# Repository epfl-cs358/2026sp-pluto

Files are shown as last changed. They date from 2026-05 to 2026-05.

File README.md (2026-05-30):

<div align="center">

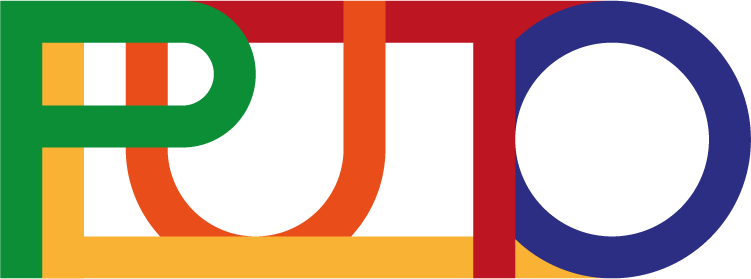
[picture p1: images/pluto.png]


# 🐶 Pluto

**A compact 12-DOF quadruped robot with ESP32 gait control, calibrated servo actuation, sensor reactions, controller-side speech commands, and simulation assets.**








</div>

<p align="center">
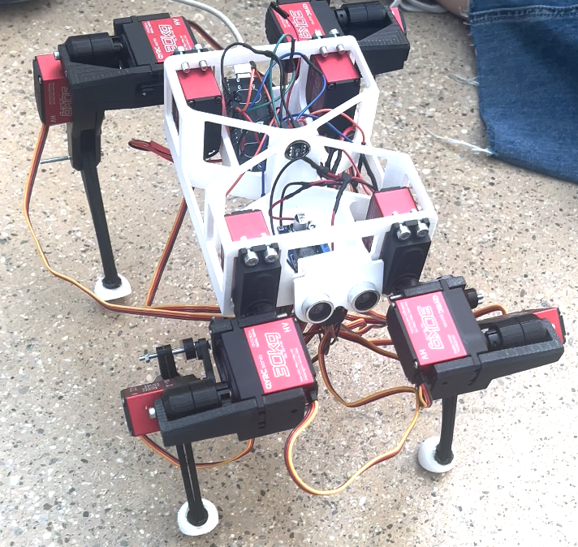
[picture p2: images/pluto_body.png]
Pluto physical robot
  
</p>

---

## 🧭 Quick Navigation

<table>
<tr>
<td width="25%" align="center" valign="top">
<a href="ASSEMBLY.md"><strong>Build Pluto</strong></a><br>
Assembly steps, leg construction, body integration, and final checks.
</td>
<td width="25%" align="center" valign="top">
<a href="WIRING_ELECTRICAL.md"><strong>Wire Pluto</strong></a><br>
Power path, common ground, PCA9685, sensors, and safety checks.
</td>
<td width="25%" align="center" valign="top">
<a href="src/esp/README.md"><strong>ESP32 Firmware</strong></a><br>
Gaits, IK, servos, sensors, serial commands, and WiFi/UDP.
</td>
<td width="25%" align="center" valign="top">
<a href="src/control/README.md"><strong>Controller UI</strong></a><br>
NiceGUI, keyboard/gamepad input, speech commands, and telemetry.
</td>
</tr>
<tr>
<td width="25%" align="center" valign="top">
<a href="CAD_FILES.md"><strong>Meshes</strong></a><br>
Current STL inventory and MuJoCo mesh usage.
</td>
<td width="25%" align="center" valign="top">
<a href="src/comm/README.md"><strong>Protocol</strong></a><br>
Shared C++/Python UDP packet and message format.
</td>
<td width="25%" align="center" valign="top">
<a href="SIMULATION.md"><strong>Simulation</strong></a><br>
PyBullet UI path, MuJoCo bridge, and current limitations.
</td>
<td width="25%" align="center" valign="top">
<a href="TROUBLESHOOTING.md"><strong>Troubleshooting</strong></a><br>
First-time setup, firmware, power, sensors, and WiFi issues.
</td>
</tr>
</table>

---

## 📚 Table of Contents

<table>
<tr>
<td width="33%" valign="top">

- [Project Context](#project-context)
- [What Pluto Can Do](#what-pluto-can-do)
- [Current Status](#current-status)
- [Quick Start](#quick-start)

</td>
<td width="33%" valign="top">

- [System Architecture](#system-architecture)
- [Hardware Overview](#hardware-overview)
- [Software Overview](#software-overview)
- [Simulation](#simulation)

</td>
<td width="33%" valign="top">

- [Configuration and Tuning](#configuration-and-tuning)
- [Repository Structure](#repository-structure)
- [Known Limitations](#known-limitations)
- [Detailed Technical Reference](#detailed-technical-reference)

</td>
</tr>
</table>

---

## 🧠 Project Context

<table>
<tr>
<td width="50%" valign="top">

### 🎯 Vision

Pluto is designed as a reusable quadruped robotics platform rather than a single-purpose demo. The goal is to make a small robot that can stand, walk, trot, gallop, react to simple sensor events, and accept commands through serial, WiFi, UI controls, and speech.

The same concepts appear across the firmware, controller, and simulation code: leg geometry, foot targets, inverse kinematics, gait phases, calibrated servo limits, and compact command messages.

</td>
<td width="50%" valign="top">

### 🎓 Course Context

Pluto was developed as part of **CS-358 Making Intelligent Things** at **EPFL**.

The repository documents both the final implementation and the current work-in-progress state so future development can continue from the same hardware, firmware, controller, protocol, and simulation foundation.

</td>
</tr>
</table>

### 🧱 Main Implementation Layers

| Layer | Role |
| --- | --- |
| ESP32 firmware | Servo control, gait execution, ultrasonic sensing, optional microphone sensing, serial testing, and WiFi/UDP command handling |
| Python tooling | NiceGUI control hub, keyboard/gamepad input, speech command handling, telemetry display, and simulation control |
| Shared communication | C++ and Python packet/message definitions kept aligned |
| CAD and simulation assets | 3D-printing meshes, simulation meshes, `pluto.xml`, PyBullet-facing code, and MuJoCo bridge |

---

## 🚀 What Pluto Can Do

<table>
<tr>
<td width="50%" valign="top">

### 🤖 Robot Side

- Drive 12 servo joints through a PCA9685 PWM driver.
- Use per-joint calibration for coxa, femur, and tibia angles.
- Run stand, stop, forward, backward, left turn, right turn, walk, trot, gallop, flip, bow, sit, and paw motion logic.
- Update gait motion every 20 ms.
- Stop motion when the ultrasonic sensor detects a close wall.
- Keep microphone support available in the source tree; the compile-time feature flag and clap-energy walking toggle are currently disabled in `main.cpp`.
- Accept serial monitor commands for gait testing and servo trimming.
- Receive UDP commands over WiFi when configured on the same network.

</td>
<td width="50%" valign="top">

### 💻 Computer Side

- Launch a NiceGUI control hub.
- Use keyboard and browser gamepad input.
- Send repeated `MOVE_BY` messages while movement input is active; firmware maps those vectors to forward, backward, left turn, right turn, or stop.
- Trigger sit, flip, bow, give paw, and stop commands from the UI.
- Run Vosk speech recognition on the controller computer.
- Display acknowledgement and distance telemetry.
- Open the Python PyBullet simulation path.
- Maintain shared message definitions with the firmware.

</td>
</tr>
</table>

---

## 📌 Current Status

| Area | Status | Notes |
| --- | --- | --- |
| Physical robot | In progress | Main build and wiring docs exist; final gait validation still needed |
| Servo control | Implemented | Calibration lives in `src/esp/legs/leg_data.h` |
| Gaits | Implemented, tuning needed | Walk, trot, gallop, left/right turn, bow, paw, stand, and stop logic exist |
| Sensors | Implemented, tuning needed | Ultrasonic wall stop is active; microphone support exists but `PLUTO_ENABLE_MICROPHONE` and clap-control are currently commented out |
| Controller UI | Implemented | Connect button, mDNS scan, movement input, sit/flip/bow/give-paw quick actions, telemetry, speech worker |
| WiFi/UDP | Implemented, enabled in firmware | Add WiFi credentials in `setup()`; the controller discovers `_pluto._udp.local` with zeroconf |
| Meshes | Updated | 3D-printing meshes live in `src/3D printing mesh`; simulation meshes and `pluto.xml` live in `src/sim/sim_mesh` |
| PyBullet | Partial | UI path exists, but visual meshes still reference old generic filenames |
| MuJoCo | Partial | Model and C++ bridge exist, but not yet a validated physical twin |

---

## ⚡ Quick Start

### 📦 1. Install Requirements

For the Python controller:

- Python 3.13
- Desktop environment for the browser UI and simulation windows
- Audio permission if using speech commands

For the ESP32 firmware:

- PlatformIO Core or the PlatformIO VS Code extension
- ESP32 board connected over USB
- Pluto hardware assembled or a safe bench setup

For the physical robot:

- Common ground between ESP32, PCA9685, servo power, sensors, and battery system
- Buck converter output checked with a multimeter
- Servo calibration checked before full gait tests

### ▶️ 2. Run the Controller

macOS/Linux:

```bash
bash run.sh
```

Windows:

```cmd
run.bat
```

Open:

```text
http://localhost:8090
```

Useful options:

```bash
bash run.sh --reinstall
bash run.sh --port 8081
```

Manual setup, if needed:

```bash
python3.13 -m venv .venv
source .venv/bin/activate
pip install -r requirements.txt
python src/control/main.py --port 8090
```

### 🔌 3. Build and Flash the ESP32

```bash
pio run
pio run -t upload
pio device monitor -b 115200
```

If the upload port is not detected automatically:

```bash
pio device list
pio run -t upload --upload-port /dev/cu.usbserial-XXXX
```

Expected startup behavior:

- PCA9685 initializes at 50 Hz.
- Enabled sensors initialize.
- Pluto enters a stand pose.
- The serial monitor prints available commands.

### 📶 4. Configure WiFi Control

WiFi support is currently enabled in `src/esp/main.cpp`:

```cpp
#define PLUTO_ENABLE_WIFI
```

Then:

1. Configure access points with `PLUTO_SERVER.addAP(...)`.
2. Make sure the computer and ESP32 are on the same network.
3. Run the controller and open `/controller`.
4. Press `Connect & Take Control`; the Python client scans for Pluto via mDNS/zeroconf and then performs the UDP handshake.

See [SOFTWARE_WIFI.md](SOFTWARE_WIFI.md).

---

## 🚀 Build Pluto From Scratch

This is the recommended order for a new team starting with only the repository, parts, and a 3D printer.

| Phase | Goal | Main files/docs | Exit check |
| --- | --- | --- | --- |
| 1. Understand the system | Know what each subsystem does before building | `README.md`, [SOFTWARE_OVERVIEW.md](SOFTWARE_OVERVIEW.md), [HARDWARE_OVERVIEW.md](HARDWARE_OVERVIEW.md) | Team can explain firmware, controller, communication, sensors, and simulation roles |
| 2. Print parts | Produce body, holder, leg, and TPU foot parts from the current 3D-printing mesh set | [CAD_FILES.md](CAD_FILES.md), `src/3D printing mesh/` | Main body, board holder, sensor holder, TPU feet, coxa, femur, tibia, spacer, and linkage parts are printed and inspected |
| 3. Assemble one leg | Validate mechanical fit before repeating four times | [ASSEMBLY.md](ASSEMBLY.md) | One leg moves freely by hand without binding |
| 4. Assemble all legs and body | Build the full physical robot frame | [ASSEMBLY.md](ASSEMBLY.md) | Four legs are mounted with correct orientation |
| 5. Build power system | Prepare battery, switch, buck converter, grounds, and servo power | [WIRING_ELECTRICAL.md](WIRING_ELECTRICAL.md) | Buck output is measured and all grounds are common |
| 6. Wire controller and servos | Connect ESP32, PCA9685, servos, ultrasonic sensor, and microphone | [WIRING_ELECTRICAL.md](WIRING_ELECTRICAL.md), [SOFTWARE_SENSORS.md](SOFTWARE_SENSORS.md) | ESP32 flashes over USB and PCA9685 powers correctly |
| 7. Bring up firmware safely | Test stand, stop, and raw trim commands before walking | [src/esp/README.md](src/esp/README.md) | Serial monitor works and joints move in expected directions |
| 8. Calibrate servos | Tune per-joint raw limits, start values, angle ranges, and inversion flags | `src/esp/legs/leg_data.h` | Each joint can move through a safe range without hitting mechanical stops |
| 9. Test motion slowly | Validate stand, walk, trot, gallop, flip, bow, sit, and paw behavior | `src/esp/motion/gait.cpp`, [TROUBLESHOOTING.md](TROUBLESHOOTING.md) | Robot can stand reliably and execute controlled test motions |
| 10. Test controller | Configure WiFi and Python controller only after safe serial tests | [SOFTWARE_WIFI.md](SOFTWARE_WIFI.md), [src/control/README.md](src/control/README.md) | Controller connects and sends stop/behavior/movement commands |
| 11. Use simulation for iteration | Inspect gait logic and mesh assumptions before risky physical tests | [SIMULATION.md](SIMULATION.md) | Team understands current PyBullet and MuJoCo limitations |

For a new team, the most important rule is to validate one subsystem at a time. Do not test full-body walking before power, calibration, and single-joint behavior are understood.

### 🧰 From Zero To First Motion

This section is written as a handoff guide for a team that did not build the original robot. It repeats some information from the detailed docs so the README can be used as a complete starting point.

#### Step 1: Prepare the repository and tools

1. Clone the repository.
2. Install Python 3.13.
3. Install PlatformIO Core or the PlatformIO VS Code extension.
4. Confirm that `pio --version` works.
5. Confirm that the Python controller can start with `bash run.sh` or `run.bat`.
6. Do not connect the LiPo battery yet.

The goal of this step is only to verify that the computer can build firmware and run the controller UI.

#### Step 2: Print and label the parts

Print the physical robot parts from `src/3D printing mesh/`. The folders are organized by leg:

- `Front Left/`
- `Front Right/`
- `Back Left/`
- `Back Right/`

The same folder also includes the top-level `Main Body.stl`, `Board Holder.stl`, `Sensor Holder.stl`, and `TPU Foot.stl` files. Each leg folder contains that leg's coxa, femur, tibia, spacer, and linkage/bar parts. The simulation-only meshes are separate and live in `src/sim/sim_mesh/`.

Label parts as soon as they are printed. Do not mix parts between legs. The firmware also uses `TOP_LEFT`, `TOP_RIGHT`, `BOTTOM_LEFT`, and `BOTTOM_RIGHT`, so a physical mix-up can become a software calibration problem later.

Before installing any servo:

- Check that each servo fits into its printed part.
- Check that screw holes are usable.
- Check that bearings sit correctly.
- Check that the tibia linkage can move without rubbing.

#### Step 3: Assemble one leg first

Build one complete leg before building the other three.

1. Assemble the tibia with its bearing and foot.
2. Assemble the femur around the servo.
3. Attach the coxa section.
4. Connect femur and tibia with the linkage.
5. Move the leg by hand.

The leg should move smoothly without powered servos. If it binds by hand, it will bind under servo power.

#### Step 4: Assemble the body and remaining legs

After one leg is validated:

1. Assemble the other three legs.
2. Mount coxa servos into the body.
3. Mount the PCA9685.
4. Mount the buck converter.
5. Mount the ESP32.
6. Mount the ultrasonic sensor at the front.
7. Mount the microphone if used.
8. Mount the battery so it is secure but removable.

Do not power the robot from the battery yet.

#### Step 5: Wire power safely

Wire in this order:

1. LiPo connector.
2. Rocker switch.
3. Servo power rail and PCA9685 servo power input.
4. Buck converter input.
5. Buck converter output.
6. ESP32 power.
7. PCA9685 logic power and I2C.
8. Sensors.
9. Servos.

Before connecting the ESP32 or sensors to the buck converter, measure the output with a multimeter. All grounds must be connected together: battery/servo ground, PCA9685 ground, buck converter ground, ESP32 ground, and sensor ground.

#### Step 6: Verify servo channels

The firmware expects this PCA9685 channel mapping:

| Leg | Coxa | Femur | Tibia |
| --- | ---: | ---: | ---: |
| `TOP_LEFT` | 0 | 1 | 2 |
| `TOP_RIGHT` | 4 | 5 | 6 |
| `BOTTOM_LEFT` | 8 | 9 | 10 |
| `BOTTOM_RIGHT` | 12 | 13 | 14 |

Channels 3, 7, 11, and 15 are unused by the current leg abstraction.

If a servo is plugged into the wrong channel, the robot may move the wrong joint even if the code is correct.

#### Step 7: Flash firmware with the robot supported

Put the robot on a stand so the legs cannot hit the table.

Then run:

```bash
pio run
pio run -t upload
pio device monitor -b 115200
```

At this stage, use serial commands only. Do not use WiFi movement yet.

#### Step 8: Calibrate one joint at a time

Calibration is in:

```text
src/esp/legs/leg_data.h
```

Each joint has:

- `raw_min`
- `raw_max`
- `raw_stand`
- `raw_forward`
- `raw_turnleft`
- `raw_turnright`
- `raw_bow`
- `raw_sit`
- `angle_min_md`
- `angle_max_md`
- `inverted`

Use the serial monitor:

- `l` selects the next leg.
- `n` selects the next joint.
- `p` prints the selected leg, joint, and pulse.
- `+` increases raw PWM by 5.
- `-` decreases raw PWM by 5.
- `r` resets the selected joint.
- `R` resets all joints on the selected leg.

For each joint:

1. Select the leg and joint.
2. Print the current value.
3. Move slowly with `+` and `-`.
4. Stop before mechanical binding.
5. Record safe min and max raw values.
6. Choose safe standing and motion-specific raw start values.
7. Check whether direction needs `inverted = true`.
8. Rebuild and upload after editing calibration.

Only after all 12 joints are calibrated should walking be tested.

#### Step 9: Test motion in small stages

Recommended order:

1. `s`: stop and stand.
2. `1`: select walk.
3. `0`: set speed to 0%.
4. `5`: set speed to 50%.
5. `f`: test forward motion briefly.
6. `q`: test left turn briefly.
7. `e`: test right turn briefly.
8. `s`: stop.
9. `2`: select trot only after walk and turns are stable.
10. `3`: select gallop only after lower-speed gaits are stable.

If a leg moves in the wrong direction, stop and return to calibration. Do not compensate by forcing the gait constants first.

#### Step 10: Test sensors

By default, ultrasonic support is compiled and microphone support is left disabled:

```cpp
#define PLUTO_ENABLE_ULTRASONIC
// #define PLUTO_ENABLE_MICROPHONE
```

Current sensor templates:

- Ultrasonic: `SensorUltraSonic<5, 18>`
- Microphone, when re-enabled: `SensorMicrophone<26, 25, 33>`

The ultrasonic sensor stops motion if the measured distance is below 35 cm. The microphone driver and `update_microphone_control(now)` helper remain in `src/esp/main.cpp`, but the feature flag and update call are currently commented out; re-enable them only after validating the energy threshold on the real microphone.

#### Step 11: Test WiFi last

Only test WiFi control after serial movement is safe.

1. Confirm `#define PLUTO_ENABLE_WIFI` is present.
2. Add WiFi credentials with `PLUTO_SERVER.addAP(...)`.
3. Upload firmware.
4. Run the Python controller.
5. Press `Connect & Take Control`.
6. Press `Stop All` before sending movement.
7. Watch telemetry for acknowledgements.

The controller should be treated as a convenience layer, not the first debugging tool.

---

## 🏗️ System Architecture

```text
+---------------------------------------------------------+
| Python Control Hub                                      |
| NiceGUI UI, keyboard/gamepad, speech, telemetry, UDP     |
+---------------------------+-----------------------------+
                            |
                            | WiFi / UDP port 4242
                            v
+---------------------------------------------------------+
| ESP32 Firmware                                          |
| 20 ms gait loop, IK, PCA9685 output, sensors, UDP server |
+---------------------------+-----------------------------+
                            |
                            v
+---------------------------------------------------------+
| Hardware and Simulation Assets                          |
| 12 servos, 4 legs, ultrasonic, microphone, STL/MuJoCo    |
+---------------------------------------------------------+
```

<table>
<tr>
<td width="33%" valign="top">

### 🎛️ Control Layer

Runs on the user's computer.

- NiceGUI app
- keyboard/gamepad input
- Vosk speech worker
- UDP controller client
- telemetry display
- simulation controls

</td>
<td width="33%" valign="top">

### 🤖 Robot Layer

Runs on the ESP32.

- PCA9685 servo output
- leg calibration
- inverse kinematics
- gait controller
- ultrasonic checks
- optional microphone energy checks
- UDP server with mDNS advertising

</td>
<td width="33%" valign="top">

### 🔁 Shared Layer

Keeps both sides aligned.

- C++ message definitions
- Python message mirror
- packet CRC checks
- session tokens
- sequence numbers
- mesh and simulation assets

</td>
</tr>
</table>

### 💡 Why The System Is Split This Way

| Design choice | Reason |
| --- | --- |
| Keep gait and servo output on ESP32 | Servo updates and stop/stand behavior stay close to the hardware |
| Keep UI, speech, and simulation on the computer | These are heavier and easier to iterate in Python |
| Mirror message definitions in C++ and Python | The controller and robot share one compact command language |
| Keep simulation assets in the repo | Gait timing and actuator mapping can be inspected before hardware tests |

---

## 🔩 Hardware Overview

| Component | Qty | Role |
| --- | ---: | --- |
| 3D-printed body and leg parts | 1 set | Robot structure |
| DMS15-style 270-degree servos | 12 | Coxa, femur, and tibia actuation |
| PCA9685 PWM driver | 1 | 16-channel servo PWM over I2C |
| ESP32 development board | 1 | Main embedded controller |
| HC-SR04-style ultrasonic sensor | 1 | Front distance sensing |
| INMP441 I2S microphone | 1 | Audio energy sensing |
| 7.4V 2S LiPo battery | 1 | Main power source |
| LM2596 buck converter | 1 | Regulated electronics power |
| KCD1 rocker switch | 1 | Main power switching |
| Screws, bearings, servo horns, wiring | As needed | Mechanical and electrical assembly |

### 🧰 Additional Materials

- PLA/PETG filament for rigid printed parts.
- TPU filament for `TPU Foot.stl`, or rubber pads if substituting the printed foot.
- M3 and M2.5 screws for the body, legs, and servo mounting.
- Ball bearings for tibia joints.
- Jumper wires for logic signals and thicker wires for servo current.
- Soldering equipment, heat-shrink tubing, electrical tape, and cable ties.
- Multimeter for voltage, polarity, and continuity checks.
- LiPo-safe charger and LiPo-safe storage bag.

### 🧱 Current Mesh Set

<p align="center">
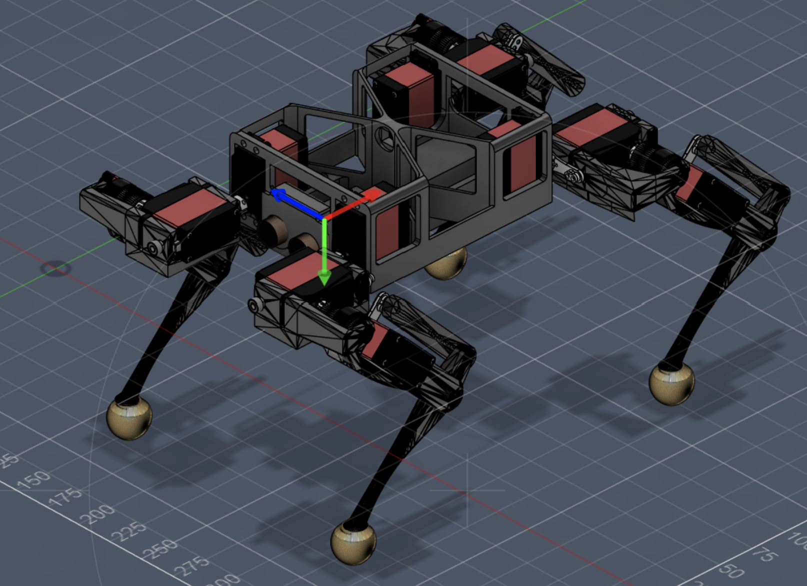
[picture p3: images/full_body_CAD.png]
Full body CAD model of Pluto
  
</p>

The current physical 3D-printing CAD/STL files live in `src/3D printing mesh/`, grouped by leg:

```text
src/3D printing mesh/
|-- Front Left/
|-- Front Right/
|-- Back Left/
`-- Back Right/
```

The physical print folder also includes `Main Body.stl`, `Board Holder.stl`, `Sensor Holder.stl`, and `TPU Foot.stl`. The simulation meshes live separately in `src/sim/sim_mesh/` and include `body.stl`, per-leg coxa/femur/tibia STL files, and `pluto.xml`. See [CAD_FILES.md](CAD_FILES.md).

### 🔄 Build Flow

<table>
<tr>
<td align="center" valign="top"><strong>1</strong><br>Print parts</td>
<td align="center" valign="top"><strong>2</strong><br>Assemble legs</td>
<td align="center" valign="top"><strong>3</strong><br>Mount electronics</td>
<td align="center" valign="top"><strong>4</strong><br>Wire power and sensors</td>
<td align="center" valign="top"><strong>5</strong><br>Flash firmware</td>
<td align="center" valign="top"><strong>6</strong><br>Calibrate servos</td>
</tr>
</table>

Detailed hardware docs:

- [ASSEMBLY.md](ASSEMBLY.md)
- [WIRING_ELECTRICAL.md](WIRING_ELECTRICAL.md)
- [HARDWARE_OVERVIEW.md](HARDWARE_OVERVIEW.md)
- [CAD_FILES.md](CAD_FILES.md)

### ⚠️ Electrical Safety Notes

| Topic | Note |
| --- | --- |
| Common ground | LiPo/servo ground, PCA9685 ground, ESP32 ground, buck converter ground, and sensor grounds must be connected together |
| Servo power | Servos draw much higher current than the ESP32 and sensors; plan the power paths separately |
| Buck converter | Adjust and measure the LM2596 output before connecting the ESP32 or sensors |
| PCA9685 | Provide both logic power and servo power, and connect SDA/SCL to the ESP32 |
| Ultrasonic ECHO | If ECHO outputs 5V, use a voltage divider or level shifter before the ESP32 GPIO |
| High-current wiring | Use appropriate wire thickness for LiPo, XT60, rocker switch, servo power rail, and PCA9685 servo power |

---

## 💻 Software Overview

For a new team, read the code in this order:

| Step | Read | Why |
| --- | --- | --- |
| 1 | `src/esp/legs/leg_data.h` | Defines the physical servo calibration assumptions |
| 2 | `src/esp/legs/leg.h` and `leg_joint.h` | Shows how servo channels and joint commands are abstracted |
| 3 | `src/esp/motion/ik_solver.cpp` | Converts foot targets into coxa/femur/tibia angles |
| 4 | `src/esp/motion/gait.cpp` | Generates stand, walk, trot, gallop, flip, bow, sit, and paw motion |
| 5 | `src/esp/main.cpp` | Connects setup, loop timing, sensors, serial commands, and WiFi |
| 6 | `src/comm/message.h` | Defines the shared C++ message format |
| 7 | `src/control/pluto_server/message.py` | Mirrors the same format in Python |
| 8 | `src/control/pluto_server/server.py` | Handles Python-side UDP connection, heartbeat, and receive loop |
| 9 | `src/control/pluto_menu/controller.py` | Converts UI input into movement and behavior messages |
| 10 | `src/control/sim_motion.py` and `src/sim/sim_main.cpp` | Shows the current simulation paths and their limitations |

### 🧠 Firmware

PlatformIO environment:

```ini
[env:esp32dev]
platform = espressif32
board = esp32dev
framework = arduino
monitor_speed = 115200
build_unflags = -std=gnu++11
build_flags = -std=gnu++17
```

PlatformIO project settings:

| Setting | Value |
| --- | --- |
| `src_dir` | `src/esp` |
| `include_dir` | `src/` |
| `build_dir` | `.build/` |
| `build_src_filter` | Excludes only paths under the firmware source root; `src/sim` is outside the ESP32 firmware build |

Important firmware files:

| File | Purpose |
| --- | --- |
| `src/esp/main.cpp` | setup, loop, feature flags, sensors, serial commands |
| `src/esp/legs/leg_data.h` | servo calibration values |
| `src/esp/legs/leg_joint.h` | calibrated servo abstraction |
| `src/esp/motion/gait.cpp` | gait and behavior motion logic |
| `src/esp/motion/ik_solver.cpp` | inverse kinematics |
| `src/esp/sensors/ultrasonic.h` | ultrasonic sensor abstraction |
| `src/esp/sensors/microphone.h` | I2S microphone abstraction |
| `src/esp/server/server.cpp` | UDP server and mDNS advertisement |

### 🎛️ Controller

Python dependencies:

```text
nicegui
numpy
debugpy
pybullet
vosk
sounddevice
zeroconf
```

Important controller files:

| File | Purpose |
| --- | --- |
| `src/control/main.py` | NiceGUI entry point |
| `src/control/pluto_menu/controller.py` | controller page, movement, behavior buttons, telemetry |
| `src/control/pluto_menu/simulation.py` | simulation page |
| `src/control/pluto_input/input_manager.py` | keyboard/gamepad movement vector |
| `src/control/pluto_server/message.py` | Python message definitions |
| `src/control/pluto_server/server.py` | UDP client, session, heartbeat, listener |
| `src/control/pluto_speech/speech.py` | Vosk speech worker |

Controller routes:

| Route | Purpose |
| --- | --- |
| `/` | Home page with simulation and controller choices |
| `/sim` | Simulation controls |
| `/controller` | Robot command center |

Current speech grammar:

- `pluto sit`
- `pluto stop`
- `pluto give paw`
- `pluto flip`
- `pluto bow`

### 🔁 Communication

The shared UDP packet contains:

| Field | Size | Purpose |
| --- | ---: | --- |
| `crc32` | 4 bytes | Packet integrity |
| `session_token` | 4 bytes | Session lock generated by ESP32 |
| `sequence_number` | 4 bytes | Stale packet rejection and acknowledgements |
| `timestamp` | 4 bytes | Sender-side local time |
| `message_count` | 1 byte | Number of valid messages |
| `messages` | 8 bytes each | Up to 64 packed messages |

Message families:

- `KIND_INFO`
- `KIND_MOVE`
- `KIND_SENSOR`
- `KIND_BEHAVIOR`

Implemented message examples:

| Message | Direction | Meaning |
| --- | --- | --- |
| `MOVE_CONTROL_BEGIN_FOR` | Python -> ESP32 | Starts a control lease |
| `MOVE_BY` | Python -> ESP32 | Carries forward/back and left/right signed 16-bit directions; firmware maps the dominant non-deadzone axis to forward, backward, left turn, right turn, or stop |
| `MOVE_STOP_FOR` | Python -> ESP32 | Stop/stand request |
| `BEHAVIOR_SIT` | Python -> ESP32 | High-level sit request; current firmware maps it to stop/stand |
| `BEHAVIOR_FLIP` | Python -> ESP32 | High-level flip request; current firmware logs the request but does not yet trigger a flip motion over UDP |
| `BEHAVIOR_BOW` | Python -> ESP32 | High-level bow request; current firmware maps it to bow motion |
| `BEHAVIOR_GIVE_PAW` | Python -> ESP32 | High-level paw request; current firmware maps it to paw motion |
| `INFO_ACKNOWLEDGE` | ESP32 -> Python | Acknowledges a packet sequence number |
| `SENSOR_DISTANCE` | ESP32 -> Python | Sends ultrasonic distance in millimeters |

Useful references:

- [SOFTWARE_OVERVIEW.md](SOFTWARE_OVERVIEW.md)
- [src/comm/README.md](src/comm/README.md)
- [SOFTWARE_WIFI.md](SOFTWARE_WIFI.md)

---

## 🎮 Simulation

| Path | Files | Current state |
| --- | --- | --- |
| Python PyBullet UI | `src/control/pluto_menu/simulation.py`, `src/control/sim_motion.py` | Integrated in the UI, but visual mesh references need updating |
| MuJoCo C++ bridge | `CMakeLists.txt`, `src/sim/sim_main.cpp`, `src/sim/sim_gait.*`, `src/sim/sim_leg.*`, `src/sim/sim_mesh/pluto.xml` | Uses current simulation meshes and simulation-side copies/adapters of the ESP leg and gait abstractions |

The MuJoCo path is more aligned with the current mesh set. The PyBullet path is still useful for UI/control experiments, but it needs a mesh update before it fully represents the current CAD assets.

The C++ MuJoCo bridge uses the top-level `CMakeLists.txt`, which sets `PLUTO_MODEL_PATH` to `src/sim/sim_mesh/pluto.xml`. Its keyboard handlers are intended to mirror the firmware test controls: `F`/`B` for forward/backward, `Q`/`E` for left/right turning, `P` for paw, `O` for flip, `S` for stop, and `1`/`2`/`3` for walk/trot/gallop. Mouse drag and scroll controls are wired through MuJoCo's camera helpers. Treat this bridge as development support until it has been rebuilt and validated on the current machine.

See [SIMULATION.md](SIMULATION.md).

---

## ⚙️ Configuration and Tuning

### 🧠 Firmware Feature Flags

Current defaults in `src/esp/main.cpp`:

```cpp
#define PLUTO_ENABLE_WIFI
#define PLUTO_ENABLE_ULTRASONIC
// #define PLUTO_ENABLE_MICROPHONE
```

| Feature | Default | Notes |
| --- | --- | --- |
| WiFi/UDP | On | Configure valid access points before using controller networking |
| Ultrasonic | On | Stops motion when wall distance is below threshold |
| Microphone | Off | `SensorMicrophone<26, 25, 33>` and clap-control code remain available, but the feature flag and update call are commented out |

### 📍 Sensor Pins and Thresholds

| Item | Current value |
| --- | --- |
| Ultrasonic template | `SensorUltraSonic<5, 18>` |
| Microphone template | `SensorMicrophone<26, 25, 33>` |
| Wall stop distance | 35 cm |
| Ultrasonic period | 150 ms |
| Microphone clap threshold | `30000000` in the commented clap-control block |
| Clap cooldown | 800 ms in the commented clap-control block |

Operating timing:

| Loop / event | Current timing |
| --- | --- |
| Gait update | 20 ms / 50 Hz |
| Ultrasonic read cycle | 150 ms |
| Ultrasonic wait after trigger | 10 ms |
| Microphone energy print cycle | 1000 ms in the commented clap-control block |
| Serial monitor baud | 115200 |

### 🎚️ Servo Calibration

Servo calibration lives in:

```text
src/esp/legs/leg_data.h
```

Each joint has:

- `raw_min`
- `raw_max`
- `raw_stand`
- `raw_forward`
- `raw_turnleft`
- `raw_turnright`
- `raw_bow`
- `raw_sit`
- `angle_min_md`
- `angle_max_md`
- `inverted`

Tune these values on the physical robot before running full gaits.

### 📐 Gait and IK Parameters

Embedded gait code lives in:

```text
src/esp/motion/gait.cpp
src/esp/motion/gait.h
```

Embedded IK code lives in:

```text
src/esp/motion/ik_solver.cpp
src/esp/motion/ik_solver.h
```

Tune these areas carefully:

- Stand pose.
- Foot target geometry.
- Stride length.
- Lift height.
- Gait period.
- Walk/trot/gallop phase offsets.
- Per-leg symmetry.
- Bow and paw target poses.

### ⌨️ Serial Commands

Use:

```bash
pio device monitor -b 115200
```

| Key | Action |
| --- | --- |
| `f` | Move forward |
| `b` | Move backward |
| `q` | Turn left |
| `e` | Turn right |
| `o` | Flip |
| `h` | Bow |
| `i` | Sit |
| `k` | Give paw |
| `s` | Stop and stand |
| `1` | Select walk gait |
| `2` | Select trot gait |
| `3` | Select gallop gait |
| `0` | Set speed to 0% |
| `5` | Set speed to 50% |
| `9` | Set speed to 100% |
| `u` | Toggle manual walk phase mode |
| `m` | Advance manual walk stage |
| `j` | Advance manual walk leg |
| `l` | Select next leg for trimming |
| `n` | Select next joint for trimming |
| `+` | Increase selected joint raw PWM by 5 |
| `-` | Decrease selected joint raw PWM by 5 |
| `r` | Reset selected joint to starting pulse |
| `R` | Reset all joints on selected leg |
| `p` | Print selected leg, joint, and pulse |

---

## 🗂️ Repository Structure

```text
2026sp-pluto/
|-- README.md
|-- ARCHIVES.md
|-- ASSEMBLY.md
|-- CAD_FILES.md
|-- HARDWARE_OVERVIEW.md
|-- ONGOING_WORK.md
|-- SIMULATION.md
|-- SOFTWARE_OVERVIEW.md
|-- SOFTWARE_SENSORS.md
|-- SOFTWARE_WIFI.md
|-- TROUBLESHOOTING.md
|-- WIRING_ELECTRICAL.md
|-- platformio.ini
|-- requirements.txt
|-- run.sh / run.bat
|-- images/
|-- scripts/
`-- src/
    |-- 3D printing mesh/ # Physical 3D-printing STL files
    |-- comm/             # Shared protocol definitions
    |-- control/          # Python UI, input, speech, and controller client
    |-- esp/              # ESP32 firmware
    `-- sim/              # C++ MuJoCo simulation bridge and sim_mesh assets
```

---

## ⚠️ Known Limitations

<table>
<tr>
<td width="50%" valign="top">

### 🔩 Hardware and Motion

- Physical gait validation is still needed.
- Servo calibration needs final tuning.
- Gait constants need real-world measurement.
- Behavior sequences need calibration.

</td>
<td width="50%" valign="top">

### 💻 Software and Simulation

- WiFi credentials still need to be configured for the target network.
- Controller discovery depends on mDNS/zeroconf working on the local network.
- UDP `MOVE_BY` messages are mapped by the ESP32 to basic gait commands, but live hardware tuning is still needed.
- PyBullet visual meshes need updating.
- MuJoCo is not yet a validated physical twin.

</td>
</tr>
</table>

See [ONGOING_WORK.md](ONGOING_WORK.md).

---

## 🔬 Detailed Technical Reference

<details>
<summary><strong>Technical vocabulary</strong></summary>

- **ESP32**: Microcontroller running the robot firmware.
- **PCA9685**: I2C PWM driver used to control the 12 servo channels.
- **12-DOF**: Twelve degrees of freedom, with three actuated joints per leg.
- **Coxa, femur, tibia**: The hip-yaw, upper-leg, and lower-leg joints.
- **IK**: Inverse kinematics, converting foot targets into joint angles.
- **Gait**: Timed leg movement pattern such as walk, trot, or gallop.
- **UDP**: Lightweight network protocol used for controller-to-robot messages.
- **CRC**: Packet integrity check used by the shared communication protocol.
- **NiceGUI**: Python web UI framework used for the control hub.
- **Vosk**: Offline speech recognition engine.
- **MuJoCo**: Physics simulator used by `src/sim/sim_mesh/pluto.xml` and the files under `src/sim/`.
- **PyBullet**: Python simulation dependency used by the control stack.

</details>

<details>
<summary><strong>Project objectives</strong></summary>

- Reliable servo control: drive 12 calibrated joints safely through the PCA9685.
- Legged locomotion: support stand, stop, forward/backward movement, left/right turns, walk, trot, gallop, flip, bow, sit, and paw motion primitives.
- IK-based movement: generate joint angles from foot targets instead of fixed pulse sequences.
- Remote operation: use a shared UDP protocol for movement, behavior, info, acknowledgement, and sensor messages.
- Sensor reactions: stop near obstacles; microphone energy code exists for clap-triggered start/stop behavior but is currently disabled by feature flag and in the main loop.
- Simulation before hardware: keep mesh and simulation assets available for gait development.
- Clear documentation: keep hardware, wiring, firmware, controller, protocol, and troubleshooting notes separated.

</details>

<details>
<summary><strong>Core technologies</strong></summary>

- **Hardware**: ESP32, PCA9685, 12 DMS15-style servos, HC-SR04-style ultrasonic sensor, INMP441 I2S microphone, 2S LiPo, LM2596 buck converter.
- **Firmware**: C++17, Arduino framework, FreeRTOS, PlatformIO, Adafruit PWM Servo Driver, Adafruit BusIO.
- **Control UI**: Python 3.13, NiceGUI, keyboard/gamepad input, Vosk, sounddevice.
- **Simulation**: PyBullet in Python, external MuJoCo/GLFW for the C++ bridge, STL mesh assets.
- **Communication**: Custom C++/Python UDP packet format with session token, sequence number, timestamp, CRC, and packed messages.

</details>

<details>
<summary><strong>ESP32 firmware responsibilities</strong></summary>

- Initialize the PCA9685 servo driver.
- Drive all 12 joints through calibrated `LegJoint` objects.
- Convert IK outputs into constrained PWM pulses.
- Update gait motion every 20 ms.
- Handle serial commands for movement, turning, gait selection, speed changes, manual walk staging, and servo trimming.
- Read ultrasonic distance and stop when a wall is too close.
- Keep the microphone driver and clap detection logic available; both are currently disabled in `main.cpp`.
- Accept UDP commands through the Pluto server when connected to WiFi.

</details>

<details>
<summary><strong>Python controller responsibilities</strong></summary>

- Serve the NiceGUI app from `src/control/main.py`.
- Provide navigation between home, simulation, and controller pages.
- Read keyboard and gamepad input through `InputManager`.
- Send repeated `MOVE_BY` messages while movement input is non-zero; the ESP32 maps them to basic movement commands.
- Send quick behavior commands for sit, flip, bow, give paw, and stop.
- Display telemetry for acknowledgements and distance readings.
- Start a Vosk speech worker on app startup.
- Start and stop simulation support from the UI.

</details>

<details>
<summary><strong>Documentation index</strong></summary>

Main system:

- [Software Overview](SOFTWARE_OVERVIEW.md)
- [Ongoing Works & Next Steps](ONGOING_WORK.md)
- [Troubleshooting](TROUBLESHOOTING.md)

Hardware:

- [Hardware Overview](HARDWARE_OVERVIEW.md)
- [Assembly Guide](ASSEMBLY.md)
- [Wiring & Electrical](WIRING_ELECTRICAL.md)
- [CAD Files](CAD_FILES.md)

Software:

- [ESP32 Firmware](src/esp/README.md)
- [Python Controller](src/control/README.md)
- [Communication Protocol](src/comm/README.md)
- [WiFi Protocol](SOFTWARE_WIFI.md)
- [Software Sensors](SOFTWARE_SENSORS.md)
- [Simulation Notes](SIMULATION.md)

Key source files:

- [Python UI entry point](src/control/main.py)
- [Controller page](src/control/pluto_menu/controller.py)
- [Simulation page](src/control/pluto_menu/simulation.py)
- [Python message definitions](src/control/pluto_server/message.py)
- [ESP firmware entry point](src/esp/main.cpp)
- [ESP gait controller](src/esp/motion/gait.cpp)
- [ESP IK solver](src/esp/motion/ik_solver.cpp)
- [Shared C++ message definitions](src/comm/message.h)
- [MuJoCo model](src/sim/sim_mesh/pluto.xml)
- [C++ simulation entry point](src/sim/sim_main.cpp)

</details>

<details>
<summary><strong>Archives and historical work</strong></summary>

The repository currently keeps most history through Git, active source files, and [ONGOING_WORK.md](ONGOING_WORK.md). If older experiments are added back for reference, they should go under an `archives/` directory with a short README explaining what was tested, why it was replaced, and whether it still runs.

Recommended archive categories:

- ESP32 experiments: old gait tests, servo calibration sketches, sensor bring-up code, and behavior prototypes.
- Control UI experiments: early NiceGUI pages, keyboard/gamepad tests, and speech command prototypes.
- Simulation experiments: PyBullet and MuJoCo model tests, gait playback experiments, and old mesh-loading attempts.
- Communication experiments: older UDP packet formats, handshake tests, and protocol debugging scripts.

See [ARCHIVES.md](ARCHIVES.md).

</details>

<details>
<summary><strong>Ongoing work and next steps</strong></summary>

Current focus:

- Hardware gait validation: test walk, trot, gallop, left/right turns, flip, bow, sit, paw, and stop on the physical robot.
- Servo calibration: refine PWM limits, standing and motion-specific starting pulses, inversion flags, and angle ranges.
- WiFi control: tune mapped UDP movement and behavior commands over mDNS-discovered connections.
- Behavior implementation: replace the current safe mapping for sit and the current UDP flip placeholder with dedicated calibrated motion sequences.
- Sensor-driven reactions: tune ultrasonic wall stopping and re-enable/tune microphone compilation and clap detection if needed.
- Simulation fidelity: improve physical accuracy for mass, friction, joint limits, and servo response.

Known issues:

- Some firmware behavior messages currently reuse safe existing motions instead of dedicated calibrated sequences.
- Some networks may block mDNS discovery, requiring controller-side fallback work.
- Gait constants need final physical measurement and tuning.
- MuJoCo and PyBullet support are useful for development, but not yet perfect models of the real robot.

</details>

---

## 👥 Project Team

Pluto was developed as part of EPFL's **CS-358 Making Intelligent Things** course by:

<table>
<tr>
<td align="center" valign="top">Serhat Botan</td>
<td align="center" valign="top">Alexis Cazal</td>
<td align="center" valign="top">Neha Chakraborty</td>
<td align="center" valign="top">Myriam Lahoud</td>
</tr>
<tr>
<td align="center" valign="top">Sam Lee</td>
<td align="center" valign="top">Raphael Dib Nehme</td>
<td align="center" valign="top">Mariya Rakytyanska</td>
</tr>
</table>

## 🙏 Acknowledgments

- EPFL course staff, TAs, and coaches.
- Open-source quadruped projects, including SpotMicro-style robots.
- Arduino, PlatformIO, FreeRTOS, Adafruit, NiceGUI, PyBullet, MuJoCo, GLFW, Vosk, and sounddevice documentation and examples.

## 🤖 Use of AI Tools

AI tools were used to support:

- Debugging guidance and code review suggestions.
- Edge-case review for setup, communication, and hardware integration notes.
- Summaries of implementation details from the codebase.

AI assistance was not used to replace:

- Project goals or engineering decision-making.
- Hardware assembly, wiring, or physical testing.
- Experimental validation on the real robot.
- Team ownership of the system design and implementation.
- Writing the instructions and README.

---

## ✅ Closing Notes

Pluto is a working foundation for a small quadruped robotics platform. The repository already contains low-level actuation, IK, gait generation, sensing hooks, controller-side interaction, command transport, and simulation assets. The next major step is careful physical tuning: servo calibration, gait stability, behavior sequences, and validation on the real robot.

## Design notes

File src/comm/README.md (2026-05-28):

# 🔁 Shared Communication Protocol

This directory contains the C++ protocol definitions shared by the ESP32 firmware and mirrored by the Python controller.

Primary file:

```text
src/comm/message.h
```

Python mirror:

```text
src/control/pluto_server/message.py
```

These two files must stay in sync.

## 📦 Packet Envelope

`UDPPacket` contains:

- `crc32`
- `session_token`
- `sequence_number`
- `timestamp`
- `message_count`
- up to 64 `Message` entries

Minimum packet size is 17 bytes. Maximum packet size is 529 bytes.

## 🔐 Session Lifecycle

A new team should understand the session flow before debugging WiFi:

1. Python sends a packet with session token `0`.
2. ESP32 treats token `0` as a session request.
3. ESP32 generates a random session token.
4. ESP32 replies with an acknowledgement packet.
5. Python stores the returned session token.
6. Python sends later packets with that token and increasing sequence numbers.
7. ESP32 rejects packets with an invalid token or old sequence number.
8. ESP32 clears the session after a timeout if no valid packets arrive.

## ✉️ Message Format

Each `Message` is exactly 8 bytes:

- 2-bit family
- 4-bit kind
- 26-bit event clock or duration field
- 32-bit payload union

Message families:

- `KIND_INFO`
- `KIND_MOVE`
- `KIND_SENSOR`
- `KIND_BEHAVIOR`

## 🧰 Implemented Helpers

`message.h` currently provides helpers for:

- `create_move_by`
- `create_control_begin`
- `create_acknowledge`
- `create_sensor_distance`
- `init_packet`
- `append_message`
- `finalize_packet_crc`
- `validate_packet`

## 🤖 Behavior Kinds

The current behavior enum is shared by `src/comm/message.h` and `src/control/pluto_server/message.py`:

| Behavior | Current firmware handling |
| --- | --- |
| `BEHAVIOR_FLIP` | Accepted over UDP and logged, but the UDP handler does not yet start a flip motion |
| `BEHAVIOR_BOW` | Starts the bow motion |
| `BEHAVIOR_SIT` | Maps to stop/stand as a safe placeholder |
| `BEHAVIOR_GIVE_PAW` | Starts the paw motion |

## ➕ Adding Or Changing A Message

The protocol is shared by firmware and Python. When adding a message:

1. Add the enum value in `src/comm/message.h`.
2. Add the same enum value in `src/control/pluto_server/message.py`.
3. Decide whether the 32-bit payload is raw data, two signed 16-bit values, an enum, or unused.
4. Add a helper constructor in both languages if the message will be sent often.
5. Update packet parsing or switch handling in `src/esp/main.cpp`.
6. Update UI, speech, or controller logic that creates the message.
7. Document the message in [SOFTWARE_WIFI.md](../../SOFTWARE_WIFI.md).

Do not change the size of `Message` or `UDPPacket` without updating both languages and the documentation.

## 📚 Related Documentation

- [WiFi Protocol](../../SOFTWARE_WIFI.md)
- [ESP32 Firmware](../esp/README.md)
- [Python Controller](../control/README.md)

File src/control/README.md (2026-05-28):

# 🎛️ Python Controller

This directory contains Pluto's computer-side control stack.

## 🚪 Entry Point

```text
src/control/main.py
```

The app uses NiceGUI and registers pages from `pluto_menu`.

Current routes:

- `/`: home page.
- `/sim`: simulation controls.
- `/controller`: robot command center.

## 🧩 Main Modules

| Module | Purpose |
| --- | --- |
| `main.py` | Starts the NiceGUI app, creates `PlutoController`, and starts the speech worker |
| `pluto_menu/controller.py` | Controller UI, connect button, behavior quick actions, movement input, and telemetry log |
| `pluto_menu/simulation.py` | PyBullet simulation UI controls |
| `pluto_input/input_manager.py` | Normalizes WASD and gamepad input into movement vectors |
| `pluto_server/message.py` | Python mirror of the shared packet/message format |
| `pluto_server/server.py` | UDP controller client, handshake, listener, and heartbeat |
| `pluto_speech/speech.py` | Vosk speech recognition worker |
| `gait.py`, `robot_config.py`, `sim_motion.py` | Python simulation and gait support |

## 🎛️ Controller Execution Flow

The control application starts in `main.py`:

1. Command-line arguments are parsed, including `--port`.
2. NiceGUI route modules are imported, which registers their pages.
3. `PlutoController` is created without a fixed robot address.
4. The controller object is stored in `app.extra`.
5. A speech-recognition worker starts in a background thread.
6. The NiceGUI server starts.

The `/controller` page then:

1. Creates an `InputManager`.
2. Tracks WASD key state.
3. Polls the first browser gamepad.
4. Combines keyboard and gamepad input into a normalized vector.
5. Converts that vector into signed 16-bit movement values scaled by `MAX_SPEED = 255`.
6. Sends `MOVE_BY` messages while the vector is non-zero.
7. Sends sit, flip, bow, give-paw, and stop messages from the quick-action buttons.
8. Reads acknowledgement and sensor messages into the telemetry log.

## ▶️ Running

Use the project-level scripts:

```bash
bash run.sh
```

or on Windows:

```cmd
run.bat
```

By default the scripts launch the UI on port `8090`.

## 📶 Robot Connection

The controller discovers Pluto at connect time. `main.py` creates the controller without a hard-coded ESP32 IP address:

```python
CONTROLLER = PlutoController()
```

When `Connect & Take Control` is pressed, `pluto_server/server.py` scans for `_pluto._udp.local.` using zeroconf/mDNS, stores the discovered IP and port, and then performs the UDP handshake. WiFi must also be enabled and configured in the ESP32 firmware with `PLUTO_ENABLE_WIFI` and valid `PLUTO_SERVER.addAP(...)` credentials.

## 👥 New-Team Setup Checklist

1. Run `bash run.sh` or `run.bat`.
2. Confirm the home page opens.
3. Open `/controller`.
4. Press WASD and confirm the displayed vector changes.
5. Connect a gamepad and confirm the vector changes.
6. Enable and configure WiFi in the ESP32 firmware.
7. Flash firmware and confirm the ESP32 is on the same network.
8. Press `Connect & Take Control`.
9. Send `Stop All` before sending movement.
10. Watch the telemetry log for `INFO_ACK` messages.

## 🎛️ Controller Page

`pluto_menu/controller.py` supports:

- Connect and take-control button with mDNS/zeroconf scanning.
- WASD keyboard input.
- First browser gamepad input.
- Repeated `MOVE_BY` messages while the movement vector is non-zero. The ESP32 maps these vectors to forward, backward, left turn, right turn, or stop.
- Quick action buttons for sit, flip, bow, give paw, and stop.
- Telemetry log for acknowledgements and distance messages.

## 🗣️ Speech Commands

Speech recognition runs on the controller computer with Vosk and `sounddevice`.

Current grammar:

- `pluto sit`
- `pluto stop`
- `pluto give paw`
- `pluto flip`
- `pluto bow`

Recognized phrases are converted into shared protocol messages.

## ➕ Adding A New UI Command

To add a new button or command:

1. Define the message in `src/control/pluto_server/message.py`.
2. Make sure the same message exists in `src/comm/message.h`.
3. Add a button or input handler in `pluto_menu/controller.py`.
4. Send the message through `pluto_controller.send_messages(...)`.
5. Add firmware handling in `src/esp/main.cpp`.
6. Test that the UI sends the packet before connecting servos.

## 🎮 Simulation Page

The `/sim` page opens the Python PyBullet path. It is useful for UI-level simulation testing, but the visual mesh references still need to be updated to match the current per-leg STL files.

Camera controls in PyBullet:

- Rotate: hold Alt/Option and left-click drag.
- Zoom: scroll wheel.
- Pan: hold middle-click drag.

See [Simulation Notes](../../SIMULATION.md).

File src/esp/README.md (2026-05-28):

# 🧠 ESP32 Firmware

This directory contains Pluto's robot-side firmware.

## 🚪 Entry Point

```text
src/esp/main.cpp
```

PlatformIO is configured with `src_dir = src/esp`, so this directory is the firmware source root.

## 🧩 Main Modules

| Module | Purpose |
| --- | --- |
| `main.cpp` | Firmware setup, loop, feature flags, ultrasonic control, gait update, serial commands, and UDP dispatch |
| `legs/leg_data.h` | Per-joint PWM and angle calibration |
| `legs/leg_joint.h` | Calibrated servo output abstraction |
| `legs/leg.h` | Three-joint leg abstraction |
| `motion/ik_solver.cpp` | Embedded inverse kinematics |
| `motion/gait.cpp` | Stand, walk, trot, gallop, turn, flip, bow, sit, paw, and gait update logic |
| `sensors/ultrasonic.h` | Ultrasonic distance sensor abstraction |
| `sensors/microphone.h` | INMP441 I2S microphone abstraction |
| `server/server.cpp` | UDP server, mDNS advertisement, sessions, CRC validation, acknowledgements, and queues |

## 🧠 Firmware Execution Flow

This is the order in which the firmware operates:

1. `setup()` starts serial output at `115200`.
2. If WiFi is enabled, `PLUTO_SERVER` is configured and starts its connection task.
3. The PCA9685 is initialized and set to 50 Hz.
4. Enabled sensors are initialized.
5. `GAIT.stand(LEGS)` moves the robot into the starting stand pose.
6. `loop()` repeatedly reads ultrasonic state; microphone control code is present but currently disabled.
7. Every 20 ms, `GAIT.update(LEGS, now)` writes updated joint targets.
8. Serial input is checked and converted into gait, speed, trimming, or reset commands.
9. If WiFi is enabled, queued UDP messages are processed.

Understanding this flow is important before adding new behavior. Long blocking code in `loop()` can make gait updates irregular.

## 🎚️ Leg and Servo Mapping

Each leg uses four PCA9685 channel slots. The current firmware uses the first three slots for coxa, femur, and tibia:

| Leg | Coxa | Femur | Tibia | Unused |
| --- | ---: | ---: | ---: | ---: |
| `TOP_LEFT` | 0 | 1 | 2 | 3 |
| `TOP_RIGHT` | 4 | 5 | 6 | 7 |
| `BOTTOM_LEFT` | 8 | 9 | 10 | 11 |
| `BOTTOM_RIGHT` | 12 | 13 | 14 | 15 |

This mapping comes from `Leg::CHANNEL_STEPS_PER_SIDE = 4` in `legs/leg.h`.

## 🎚️ Servo Calibration Workflow

Calibration lives in:

```text
src/esp/legs/leg_data.h
```

Each joint has:

- `raw_min`: lowest safe raw PWM value.
- `raw_max`: highest safe raw PWM value.
- `raw_stand`: standing raw PWM value.
- `raw_forward`: forward-start raw PWM value.
- `raw_turnleft`: left-turn-start raw PWM value.
- `raw_turnright`: right-turn/backward-start raw PWM value.
- `raw_bow`: bow-start raw PWM value.
- `raw_sit`: sit-start raw PWM value.
- `angle_min_md`: minimum logical angle in millidegrees.
- `angle_max_md`: maximum logical angle in millidegrees.
- `inverted`: whether logical angle direction is reversed for that joint.

Recommended calibration sequence:

1. Place the robot on a stand so legs can move freely.
2. Use serial command `l` to select a leg.
3. Use serial command `n` to select a joint.
4. Use `p` to print the current selected joint and pulse.
5. Use `+` and `-` to move in small raw PWM increments.
6. Record the safe lower and upper values before mechanical binding.
7. Set `raw_stand` to a physically neutral standing value, then tune the motion-specific raw start values.
8. Confirm whether the logical direction needs `inverted = true`.
9. Repeat for all 12 joints.
10. Rebuild and upload firmware after changing calibration values.

Do not run full gait commands until all 12 joints have safe limits.

## 🚩 Feature Flags

Current defaults in `main.cpp`:

```cpp
#define PLUTO_ENABLE_WIFI
#define PLUTO_ENABLE_ULTRASONIC
// #define PLUTO_ENABLE_MICROPHONE
```

That means WiFi/UDP and ultrasonic support are enabled at compile time. Microphone support remains in the source tree, but the feature flag is currently commented out. WiFi still needs valid access point credentials in `setup()`.

## 📌 Timing

- Gait update: every 20 ms.
- Ultrasonic cycle: every 150 ms.
- Ultrasonic wait after trigger: 10 ms.
- Microphone clap-control code and the microphone feature flag are currently commented out in `main.cpp`.
- Serial baud rate: 115200.

## 📡 Sensors

Current sensor templates in `main.cpp`:

- Ultrasonic: `SensorUltraSonic<5, 18>`
- Microphone, when re-enabled: `SensorMicrophone<26, 25, 33>`

Motion stops if ultrasonic distance is between 0 and 35 cm.

The microphone driver does not initialize with the current default flags. Re-enable `PLUTO_ENABLE_MICROPHONE` and the `update_microphone_control(now)` call only after validating the energy threshold on the real microphone.

## ⌨️ Serial Commands

Use:

```bash
pio device monitor -b 115200
```

| Key | Action |
| --- | --- |
| `f` | Move forward |
| `b` | Move backward |
| `o` | Flip |
| `h` | Bow |
| `i` | Sit |
| `k` | Give paw |
| `s` | Stop and stand |
| `1` | Select walk gait |
| `2` | Select trot gait |
| `3` | Select gallop gait |
| `0` | Set speed to 0% |
| `5` | Set speed to 50% |
| `9` | Set speed to 100% |
| `u` | Toggle manual walk phase mode |
| `m` | Advance manual walk stage |
| `j` | Advance manual walk leg |
| `l` | Select next leg for trimming |
| `n` | Select next joint for trimming |
| `+` | Increase selected joint raw PWM by 5 |
| `-` | Decrease selected joint raw PWM by 5 |
| `r` | Reset selected joint to starting pulse |
| `R` | Reset all joints on selected leg |
| `p` | Print selected leg, joint, and pulse |

## 📶 WiFi/UDP

When `PLUTO_ENABLE_WIFI` is enabled, the firmware creates:

```cpp
auto PLUTO_SERVER = pluto::PlutoServer{4242};
```

Configure access points in `setup()` with:

```cpp
PLUTO_SERVER.addAP("<WIFI_NAME>", "<WIFI_PASSWORD>");
```

Queued UDP messages are processed in `loop()`. `MOVE_BY` commands apply a small deadzone and then map to one of the existing movement commands:

The mDNS service is advertised as `_pluto._udp.local` after the ESP32 is connected to WiFi. If WiFi disconnects, the firmware stops UDP listening, ends mDNS, and clears the active session.

- positive forward/back value: walk forward
- negative forward/back value: walk backward
- negative left/right value: turn left
- positive left/right value: turn right
- both axes inside the deadzone: stop and stand

Behavior messages currently map as follows:

- `BEHAVIOR_SIT`: stop/stand
- `BEHAVIOR_FLIP`: accepted and logged, but no UDP-triggered flip motion yet
- `BEHAVIOR_BOW`: bow motion
- `BEHAVIOR_GIVE_PAW`: paw motion

See [WiFi Protocol](../../SOFTWARE_WIFI.md) and [Shared Communication Protocol](../comm/README.md).

## 📌 Build and Upload

From the repository root:

```bash
pio run
pio run -t upload
pio device monitor -b 115200
```

## 🧠 Adding New Firmware Behavior

To add a new robot behavior:

1. Add or reuse a `MessageBehaviorKind` in `src/comm/message.h`.
2. Mirror it in `src/control/pluto_server/message.py`.
3. Add UI or speech trigger code in `src/control`.
4. Add firmware handling in the `KIND_BEHAVIOR` switch in `src/esp/main.cpp`.
5. Implement the motion in `src/esp/motion/gait.cpp` if it needs continuous updates.
6. Test over serial first when possible.
7. Test over UDP only after serial behavior is safe.

Keep behavior code non-blocking. Prefer stateful motion updated by the 20 ms gait loop instead of long delays inside message handling.

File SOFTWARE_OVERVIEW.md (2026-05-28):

# 💻 Software Overview

Pluto's software is split into four active areas: ESP32 firmware, Python controller, shared communication protocol, and simulation support.

## 🧰 How To Read The Code From Scratch

For a new team, read the code in this order:

| Step | File or folder | What to learn |
| --- | --- | --- |
| 1 | `platformio.ini` | How PlatformIO builds the ESP32 firmware from `src/esp` |
| 2 | `src/esp/legs/leg_data.h` | Servo calibration values and leg names |
| 3 | `src/esp/legs/leg.h` | Servo channel mapping and leg abstraction |
| 4 | `src/esp/legs/leg_joint.h` | How raw PWM and logical angles are written |
| 5 | `src/esp/motion/ik_solver.cpp` | How foot targets become joint angles |
| 6 | `src/esp/motion/gait.cpp` | How stand, walk, trot, gallop, bow, and paw are generated |
| 7 | `src/esp/main.cpp` | Firmware startup, feature flags, sensors, serial commands, and UDP dispatch |
| 8 | `src/comm/message.h` | Shared C++ packet and message format |
| 9 | `src/control/pluto_server/message.py` | Python mirror of the same packet and message format |
| 10 | `src/control/pluto_server/server.py` | Python UDP client, connection handshake, heartbeat, and listener |
| 11 | `src/control/main.py` | NiceGUI app entry point and controller setup |
| 12 | `src/control/pluto_menu/controller.py` | How keyboard/gamepad input becomes robot messages |
| 13 | `src/control/pluto_speech/speech.py` | How recognized speech becomes robot messages |
| 14 | `src/control/sim_motion.py` and `src/sim/sim_main.cpp` | Current Python and MuJoCo simulation paths |

Read this before changing behavior. Most software bugs in this project come from changing one side of a shared contract without updating the matching side.

## 📌 Main Components

| Component | Location | Role |
| --- | --- | --- |
| ESP32 firmware | [src/esp](src/esp/README.md) | Runs on the robot, controls servos, executes gaits, reads sensors, and optionally handles UDP packets |
| Python control hub | [src/control](src/control/README.md) | Provides the NiceGUI interface, PyBullet control page, keyboard/gamepad input, speech worker, and UDP client |
| Shared protocol | [src/comm](src/comm/README.md) | Defines the compact packet and message format shared by C++ firmware and Python control code |
| Simulation assets | [SIMULATION.md](SIMULATION.md) | Documents the Python PyBullet path, MuJoCo XML model, C++ bridge, and current limitations |
| WiFi protocol notes | [SOFTWARE_WIFI.md](SOFTWARE_WIFI.md) | Documents UDP connection setup, packet structure, batching, CRCs, and payload layout |
| Sensor notes | [SOFTWARE_SENSORS.md](SOFTWARE_SENSORS.md) | Documents the ultrasonic distance sensor, INMP441 microphone, and current firmware behavior |

## 🧠 Firmware Layer

The ESP32 firmware handles time-sensitive robot behavior:

- PCA9685 initialization and 12-servo PWM output.
- Per-joint calibration through `LegJoint` and `leg_data.h`.
- Inverse kinematics for coxa, femur, and tibia joints.
- Gait generation for stand, walk, trot, gallop, turns, flip, bow, sit, paw, and stop.
- Serial monitor command handling for testing and trimming.
- Ultrasonic wall-stop behavior.
- Microphone driver and clap-toggle logic are present, but currently disabled in `main.cpp`.
- FreeRTOS-based UDP communication with mDNS service advertisement when `PLUTO_ENABLE_WIFI` is enabled.

Current default feature flags in `src/esp/main.cpp`:

```cpp
#define PLUTO_ENABLE_WIFI
#define PLUTO_ENABLE_ULTRASONIC
// #define PLUTO_ENABLE_MICROPHONE
```

See [ESP32 Firmware](src/esp/README.md).

### 🧠 Firmware Bring-Up Order

Use this sequence when setting up a new robot:

1. Build firmware without changing feature flags.
2. Upload to ESP32 and open serial monitor.
3. Verify PCA9685 startup and stand pose.
4. Test `s`, `p`, `l`, `n`, `+`, `-`, and `r` before walking.
5. Tune `src/esp/legs/leg_data.h`.
6. Test `1`, `2`, `3` gait selection without aggressive speeds.
7. Validate WiFi control only after serial control is safe.

## 🎛️ Control Layer

The Python control hub provides operator-facing tools:

- NiceGUI home, simulation, and controller pages.
- Keyboard and browser gamepad input normalization.
- `MOVE_BY` command sending while movement input is non-zero; firmware maps the vectors to forward, backward, left turn, right turn, or stop.
- Quick behavior buttons for sit, give paw, and stop.
- Telemetry display for acknowledgements and distance messages.
- Vosk-based speech commands using the controller computer microphone.
- UDP packet creation and session handling through `PlutoController`.

The controller discovers the ESP32 with zeroconf/mDNS when `Connect & Take Control` is pressed.

See [Python Controller](src/control/README.md).

### 🎛️ Controller Bring-Up Order

Use this sequence when setting up the controller:

1. Run `bash run.sh` or `run.bat`.
2. Confirm the NiceGUI home page opens.
3. Open `/controller` and check that keyboard vectors update.
4. Confirm `PLUTO_ENABLE_WIFI` is enabled and WiFi credentials are configured in firmware.
5. Connect from the controller page.
6. Test `Stop All` before movement.
7. Test a small movement vector.
8. Check telemetry for acknowledgements.

## 🔁 Communication Layer

Python and C++ share a compact binary protocol. Commands are grouped into UDP packets with:

- CRC validation.
- Session tokens.
- Sequence numbers.
- Device timestamps.
- Up to 64 packed 8-byte messages per packet.

See [Communication](src/comm/README.md) and [WiFi Protocol](SOFTWARE_WIFI.md).

### 🔁 Keeping Protocol Files In Sync

Whenever a message family, kind, payload, or packet field changes:

1. Update `src/comm/message.h`.
2. Update `src/control/pluto_server/message.py`.
3. Update [src/comm/README.md](src/comm/README.md).
4. Test packing and unpacking on the Python side.
5. Flash firmware and test one packet type at a time.

## 🎮 Simulation Layer

Pluto currently has two simulation-facing paths:

- Python PyBullet control path under `src/control`.
- MuJoCo XML model and C++ simulation bridge under `src/sim/sim_mesh` and `src/sim`.

The MuJoCo model uses the current per-leg STL files. The Python PyBullet visual path is older and still expects generic leg mesh filenames, so it needs a mesh update to fully match the current CAD set.

See [Simulation Notes](SIMULATION.md).

## 📌 Current Extension Points

- Better gait stability and interpolation.
- Live WiFi control tuning on hardware.
- More complete behavior sequences.
- Higher-fidelity simulation.
- Autonomous obstacle avoidance.

See [Ongoing Works & Next Steps](ONGOING_WORK.md).

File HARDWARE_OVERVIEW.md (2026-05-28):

# 🔩 Hardware Overview

Pluto is a compact 12-servo quadruped robot. The hardware is organized around a 3D-printed body, four modular 3-DOF legs, an ESP32 controller, a PCA9685 servo driver, LiPo power, ultrasonic distance sensing, and microphone input.

## 🔩 Main Hardware Areas

| Area | Purpose | Details |
| --- | --- | --- |
| Mechanical structure | Holds electronics and supports four articulated legs | Current per-leg meshes are listed in [CAD Files](CAD_FILES.md) |
| Leg actuation | Provides 3 degrees of freedom per leg | 12 DMS15-style 270-degree servos: coxa, femur, and tibia on each leg |
| Servo control | Drives all servos with stable PWM | PCA9685 16-channel PWM driver over I2C |
| Main controller | Runs firmware, sensors, gait logic, and WiFi/UDP | ESP32 development board |
| Sensing | Provides basic environment and audio input | HC-SR04-style ultrasonic sensor and INMP441 I2S microphone |
| Power | Supplies servo and logic power | 7.4V 2S LiPo, XT60 connectors, rocker switch, and LM2596 buck converter |

## 🔢 Build Order

1. Print the body, holder, leg, and TPU foot parts from the current physical 3D-printing mesh set in `src/3D printing mesh`.
2. Assemble each coxa/femur/tibia leg chain with servos, horns, bearings, and linkage hardware.
3. Mount the coxa servos, PCA9685, buck converter, ESP32, sensors, and battery in the body.
4. Wire the power system first, then I2C, servo channels, and sensor connections.
5. Verify voltage levels and polarity before connecting all servos.
6. Flash the ESP32 firmware and test basic serial commands before running full gaits.

## 🔩 From-Scratch Hardware Milestones

Use these milestones to know when it is reasonable to move to the next stage:

| Milestone | What must be true |
| --- | --- |
| Mechanical prototype | One leg can be assembled and moved by hand without binding |
| Full frame | Four legs are mounted and have consistent orientation |
| Power system | Battery, switch, buck converter, and common ground are verified with a multimeter |
| Servo wiring | Each PCA9685 channel controls the expected joint |
| Sensor wiring | Ultrasonic and microphone pins match `src/esp/main.cpp` |
| Firmware bring-up | Serial monitor commands work before walking is attempted |
| Calibration | Every joint has safe `raw_min`, `raw_max`, standing raw, and motion-specific start values |

## 🔩 Important Hardware Notes

- All electronics and servo power paths must share a common ground.
- The servos can draw large current spikes, so use appropriate wire thickness for the servo power rail.
- Check the LM2596 output with a multimeter before powering the ESP32 or sensors from it.
- Confirm the ultrasonic ECHO voltage before connecting it directly to an ESP32 pin.
- Calibrate servo limits in firmware before testing full body movements.

## 📚 Documentation

- [Assembly Instructions](ASSEMBLY.md): leg assembly, body assembly, and final integration.
- [Wiring & Electrical](WIRING_ELECTRICAL.md): power path, circuit diagram, ESP32, PCA9685, sensors, and startup checks.
- [CAD Files](CAD_FILES.md): current mesh files and 3D-printing notes.
- [Software Sensors](SOFTWARE_SENSORS.md): ultrasonic and microphone software notes.
- [Troubleshooting](TROUBLESHOOTING.md): first-time setup and failure checks.

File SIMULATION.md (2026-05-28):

# 🎮 Simulation Notes

Pluto currently has two simulation-facing paths. They are useful for development, but they are not yet a single polished, high-fidelity simulator.

## 🎮 Current Simulation Paths

| Path | Files | Status |
| --- | --- | --- |
| Python PyBullet UI | `src/control/pluto_menu/simulation.py`, `src/control/sim_motion.py`, `src/control/gait.py` | Integrated into the NiceGUI control hub, but the visual mesh loading still expects older generic mesh filenames |
| MuJoCo C++ bridge | `CMakeLists.txt`, `src/sim/sim_main.cpp`, `src/sim/sim_gait.*`, `src/sim/sim_leg.*`, `src/sim/sim_mesh/pluto.xml` | Uses the current per-leg mesh set and simulation-side leg/gait abstractions based on the ESP concepts |

## 🎮 How A New Team Should Use Simulation

Use simulation to inspect concepts, not to prove that hardware walking is safe.

Recommended order:

1. Read `src/control/gait.py` and `src/control/robot_config.py` to understand Python-side gait assumptions.
2. Read `src/esp/motion/gait.cpp` to understand firmware-side gait assumptions.
3. Inspect `src/sim/sim_mesh/pluto.xml` to see how the current mesh set is represented in MuJoCo.
4. Use the PyBullet UI path for controller and UI experiments.
5. Use the MuJoCo bridge to inspect how ESP gait output maps to simulated actuators.
6. Treat simulation success as a sign to continue testing, not as proof that the physical robot is safe.
7. Validate all physical movement slowly on the real robot with conservative calibration.

## 🎮 Python PyBullet Path

The `/sim` page in the NiceGUI app can open a PyBullet window and send basic motion commands through `PyBulletMotionController`.

Important files:

- `src/control/pluto_menu/simulation.py`: NiceGUI page and motion buttons.
- `src/control/sim_motion.py`: PyBullet process, robot construction, and command queue.
- `src/control/gait.py`: Python gait definitions.
- `src/control/robot_config.py`: Python simulation geometry constants.

Current limitation:

`src/control/sim_motion.py` still references generic visual mesh files:

- `coxa.stl`
- `femur.stl`
- `tibia.stl`

Those files are not part of the current mesh set. The active repository now stores per-leg files such as `tl_coxa.stl`, `tr_femur.stl`, and `br_tibia.stl`. Until `sim_motion.py` is updated, the PyBullet visual mesh path may fail or render without the intended current parts.

To update this path, replace the generic mesh references in `sim_motion.py` with the current per-leg STL files and verify the visual frame offsets for each leg.

## 🎮 MuJoCo Path

Why use MuJoCo in this project:

- Better sim-to-real potential: MuJoCo gives stronger contact and dynamics behavior for legged motion tuning, so gait behavior in simulation is more likely to transfer to hardware than a purely UI-focused path.
- C++ integration: the simulator bridge is already implemented in C++ and mirrors ESP-side concepts, which makes it easier to reuse control logic and keep firmware/simulation assumptions aligned.

The MuJoCo model is stored in:

```text
src/sim/sim_mesh/pluto.xml
```

It references the current mesh files:

- `body.stl`
- `tl_coxa.stl`, `tl_femur.stl`, `tl_tibia.stl`
- `tr_coxa.stl`, `tr_femur.stl`, `tr_tibia.stl`
- `bl_coxa.stl`, `bl_femur.stl`, `bl_tibia.stl`
- `br_coxa.stl`, `br_femur.stl`, `br_tibia.stl`

The C++ bridge is stored in:

```text
src/sim/sim_main.cpp
src/sim/sim_gait.cpp
src/sim/sim_gait.h
src/sim/sim_leg.h
src/sim/sim_leg_joint.h
CMakeLists.txt
```

It constructs simulation-side `Leg` objects, runs a simulation-side `GaitController`, converts current joint angles to radians, and writes them to 12 MuJoCo actuators.

### ▶️ Build and Run the MuJoCo Bridge

The MuJoCo bridge is built with the top-level `CMakeLists.txt`, not PlatformIO. MuJoCo must be downloaded separately, then CMake must be pointed at that local installation.

```bash
cmake -S . -B build -DMUJOCO_DIR=/path/to/mujoco
cmake --build build
./build/bin/pluto_sim
```

On Windows, the default path is `C:/mujoco`, and the build copies MuJoCo DLLs from `MUJOCO_DIR/bin` beside the executable. On macOS or Linux, pass the actual MuJoCo install path with `-DMUJOCO_DIR=...`.

The model path is compiled into the executable as:

```text
PLUTO_MODEL_PATH="${CMAKE_SOURCE_DIR}/src/sim/sim_mesh/pluto.xml"
```

The bridge currently supports keyboard commands:

| Key | Action |
| --- | --- |
| `F` | Move forward |
| `B` | Move backward |
| `Q` | Turn left |
| `E` | Turn right |
| `P` | Give paw |
| `O` | Flip |
| `S` | Stop |
| `1` | Walk gait |
| `2` | Trot gait |
| `3` | Gallop gait |

Mouse controls are handled through MuJoCo camera helpers:

- Left drag rotates the camera.
- Right drag moves the camera vertically or horizontally with Shift.
- Middle drag zooms.
- Scroll zooms in and out.

Simulation demo video: [images/simulation.mp4](images/simulation.mp4)

## 🎮 Known Simulation Limitations

- The simulation is not yet a validated physical twin of Pluto.
- Mass, friction, joint constraints, servo torque, cable effects, and battery placement still need refinement.
- Python PyBullet and C++ MuJoCo paths are separate and not yet unified.
- The PyBullet visual mesh path needs to be updated to use the current per-leg mesh files.
- The MuJoCo bridge is not part of the PlatformIO ESP32 firmware build.
- The top-level `CMakeLists.txt` defines the MuJoCo executable and sets `PLUTO_MODEL_PATH` to `src/sim/sim_mesh/pluto.xml`.

## 🎮 Future Simulation Work

For a future team, useful improvements would be:

- Unify the Python and MuJoCo simulation assumptions.
- Replace old PyBullet generic mesh references with current per-leg meshes.
- Tune mass, friction, joint limits, and servo response against physical measurements.

## 📚 Related Documentation

- [Software Overview](SOFTWARE_OVERVIEW.md)
- [CAD Files](CAD_FILES.md)
- [Python Controller](src/control/README.md)
- [ESP32 Firmware](src/esp/README.md)

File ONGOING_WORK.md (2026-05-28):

# 🚧 Ongoing Works & Next Steps

Pluto is still under active development. The current codebase already provides the main building blocks for locomotion, simulation, sensing, and communication, but several parts need tuning and integration before the robot behaves as a robust autonomous platform.

## 📌 Current Focus

- Hardware gait validation: test walk, trot, gallop, left/right turns, flip, bow, sit, paw, and stop on the physical robot.
- Servo calibration: refine each joint's PWM limits, standing and motion-specific starting pulses, inversion flag, and angle range so IK commands map safely to physical motion.
- WiFi control validation: configure access points, verify mDNS/zeroconf discovery, and tune the mapped UDP movement commands on hardware.
- Behavior implementation: replace the current safe mapping for sit and the current UDP flip placeholder with dedicated calibrated motion sequences.
- Sensor-driven reactions: tune ultrasonic wall stopping and re-enable/tune microphone compilation and clap detection if needed.
- Simulation cleanup: update the Python PyBullet visual mesh path to use the current per-leg STL files and continue refining the MuJoCo model.

## 🛠️ Improvements

- Add a formal robot state machine for idle, standing, walking, behavior execution, and emergency stop.
- Smooth gait transitions so switching between stand, walk, trot, gallop, and stop does not create abrupt servo jumps.
- Add interpolation and trajectory limits around IK outputs to reduce mechanical stress.
- Improve connection-state and WiFi-status visibility in the controller UI.
- Add optional IMU feedback for body orientation and gait stability.
- Extend simulation so it better matches physical mass, friction, joint limits, and servo behavior.
- Add a telemetry view for connection state, latest distance reading, gait mode, speed, and acknowledgements.
- Document final servo channel mapping after hardware validation.

## 📌 Known Issues

- Some ESP32 behavior messages currently reuse safe existing motions instead of dedicated calibrated sequences.
- Some networks may block mDNS discovery, so a manual-IP fallback may still be useful.
- Gait constants in ESP firmware still need final physical measurements and tuning.
- The Python PyBullet visual path still references old generic mesh filenames.
- MuJoCo support is useful for development, but it is not yet a validated physical twin.

## 🔮 Future Directions

- Improve autonomous obstacle avoidance using ultrasonic sensing and later camera-based perception.
- Add expressive behaviors such as crouching, paw gestures, recovery motions, and more reliable sitting/lying poses.
- Explore AprilTags, camera streaming, or simple visual navigation once the base locomotion is stable.
- Use Pluto as a reusable teaching platform for legged locomotion, robot control, and embedded sensing.

## 📚 Related Documentation

- [README.md](README.md)
- [SOFTWARE_OVERVIEW.md](SOFTWARE_OVERVIEW.md)
- [SIMULATION.md](SIMULATION.md)
- [TROUBLESHOOTING.md](TROUBLESHOOTING.md)

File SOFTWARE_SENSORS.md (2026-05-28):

# 💻 Software Sensors

Pluto currently has two firmware sensor abstractions: an ultrasonic distance sensor and an INMP441 I2S microphone.

## 🧠 Current Firmware Defaults

Current sensor defaults in [src/esp/main.cpp](src/esp/main.cpp):

```cpp
#define PLUTO_ENABLE_ULTRASONIC
// #define PLUTO_ENABLE_MICROPHONE
```

Current pin templates:

- Ultrasonic sensor: `SensorUltraSonic<5, 18>`
- Microphone, when re-enabled: `SensorMicrophone<26, 25, 33>`

Verify these pins against the physical wiring before flashing or powering the robot.

## 🧰 Sensor Bring-Up From Scratch

Bring up sensors after the ESP32, PCA9685, and basic servo tests work.

1. Confirm both sensors share ground with the ESP32.
2. Confirm the ultrasonic ECHO voltage is safe for the ESP32. Use a level shifter or voltage divider if needed.
3. Flash firmware with `PLUTO_ENABLE_ULTRASONIC` enabled first.
4. Open the serial monitor at `115200`.
5. Move an object in front of the ultrasonic sensor and confirm wall-stop behavior.
6. If microphone behavior is needed, re-enable `PLUTO_ENABLE_MICROPHONE` and `update_microphone_control(now)` in `main.cpp`, then tune the clap threshold before using it near powered servos.
7. If sensor behavior is unstable, test one sensor at a time by disabling the other feature flag.

## 📏 Ultrasonic Sensor

The ultrasonic abstraction is implemented in:

```text
src/esp/sensors/ultrasonic.h
```

It is designed around a non-blocking read pattern:

- `read_begin()` sends the trigger pulse.
- `read_end()` collects the measured pulse duration and converts it to distance.

The current firmware starts a read every 150 ms and checks the result roughly 10 ms later. If the measured distance is positive and below 35 cm, `stop_robot("wall too close")` is called.

The sensor is intended for simple front obstacle detection.

### 📝 Ultrasonic Integration Notes

- The firmware does not block while waiting for the ultrasonic echo.
- `read_begin()` starts the measurement.
- The main loop waits briefly before `read_end()`.
- The current stop condition applies whenever the distance is below the threshold.
- Current wall-stop threshold is 35 cm.

This sensor is a safety and interaction feature, not a full mapping sensor.

## 🎙️ Microphone

The microphone abstraction is implemented in:

```text
src/esp/sensors/microphone.h
```

It uses I2S and exposes:

```cpp
current_energy()
```

This returns a dimensionless relative audio energy value. The clap-control block exists in `main.cpp`, but the microphone feature flag is currently commented out and `update_microphone_control(now)` is not called from the loop.

Current commented clap-control settings:

- Clap threshold: `30000000`
- Clap cooldown: `800 ms`
- Behavior if re-enabled: if the robot is walking, a clap stops it; otherwise a clap starts walking.

### 📝 Microphone Integration Notes

- The ESP32 microphone code measures energy, not full speech.
- Speech recognition is intentionally handled by the controller computer.
- The clap threshold is empirical and should be tuned in the real environment.
- If the robot starts or stops accidentally, increase the threshold or add filtering.

## 🗣️ Speech Recognition

The ESP32 firmware does not run speech recognition. Spoken commands are handled on the controller computer by Vosk in:

```text
src/control/pluto_speech/speech.py
```

Currently supported phrases include:

- `pluto sit`
- `pluto stop`
- `pluto give paw`
- `pluto flip`
- `pluto bow`

The controller converts recognized phrases into shared protocol messages and sends them to the ESP32 when connected.

## 📚 Related Documentation

- [Wiring & Electrical](WIRING_ELECTRICAL.md)
- [ESP32 Firmware](src/esp/README.md)
- [Python Controller](src/control/README.md)
- [Troubleshooting](TROUBLESHOOTING.md)

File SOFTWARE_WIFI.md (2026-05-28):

# 🔁 WiFi Protocol

Pluto's controller and ESP32 firmware can communicate over WiFi using UDP on port `4242`.

WiFi support is implemented in the codebase and is currently enabled in [src/esp/main.cpp](src/esp/main.cpp):

```cpp
#define PLUTO_ENABLE_WIFI
```

Configure valid access points before expecting the ESP32 to join the network or receive controller messages.

## ⚙️ Configuration

### 📌 ESP32 Access Points

When `PLUTO_ENABLE_WIFI` is enabled, configure access points in `setup()`:

```cpp
PLUTO_SERVER.addAP("<WIFI_NAME>", "<WIFI_PASSWORD>");
```

Multiple calls are allowed. The ESP32 uses `WiFiMulti` and tries available configured networks.

### 📌 Python Discovery

The Python controller is constructed without a hard-coded ESP32 address in [src/control/main.py](src/control/main.py):

```python
CONTROLLER = PlutoController()
```

When the user presses `Connect & Take Control`, the controller scans for `_pluto._udp.local.` using zeroconf/mDNS. The ESP32 advertises that UDP service as `pluto` on port `4242`.

## 🧰 WiFi Bring-Up From Scratch

Only test WiFi control after serial control and servo safety are working.

1. Confirm `PLUTO_ENABLE_WIFI` is defined in `src/esp/main.cpp`.
2. Add at least one valid `PLUTO_SERVER.addAP(...)` call.
3. Upload firmware and open the serial monitor.
4. Confirm the ESP32 joins the expected network.
5. Run `bash run.sh` or `run.bat`.
6. Open `/controller`.
7. Press `Connect & Take Control`.
8. Send `Stop All` first.
9. Check for acknowledgement messages in the telemetry log.
10. Send small movement inputs only after stop and behavior messages work. The ESP32 maps `MOVE_BY` vectors to forward, backward, left turn, right turn, or stop.

If connection fails, debug network reachability before debugging gait code.

## 🔐 Session Flow

The Python controller performs a UDP handshake before sending normal messages:

1. Python sends an empty packet with session token `0`.
2. ESP32 accepts token `0` as a session request.
3. ESP32 generates a random session token.
4. ESP32 replies with an acknowledgement packet.
5. Python stores the session token and starts listener and heartbeat threads.
6. Later packets must use the session token and increasing sequence numbers.

The ESP32 session times out after 10 seconds without valid packets.

## 📦 Packet Format

The packet format is defined in:

- [src/comm/message.h](src/comm/message.h)
- [src/control/pluto_server/message.py](src/control/pluto_server/message.py)

Each UDP packet contains:

| Field | Size | Purpose |
| --- | ---: | --- |
| `crc32` | 4 bytes | Integrity check over the packet after the CRC field |
| `session_token` | 4 bytes | Session lock generated by the ESP32 |
| `sequence_number` | 4 bytes | Monotonic packet sequence for acknowledgement and stale-packet rejection |
| `timestamp` | 4 bytes | Sender-side local time in milliseconds |
| `message_count` | 1 byte | Number of valid messages in the packet |
| `messages` | 8 bytes each | Up to 64 packed messages |

Minimum packet size is 17 bytes. Maximum packet size is 529 bytes.

## ✉️ Message Format

Each message is exactly 8 bytes:

```text
  Bit 0   2      6                                32
      +---+------+---------------------------------+
Header|Fam| Kind |     event_clock_or_duration     |
      | 2 |  4   |             26 bits             |
      +---+------+---------------------------------+
      |                                            |
      |                  payload                   |
      |                  32 bits                   |
      +--------------------------------------------+
```

Message families:

- `KIND_INFO`
- `KIND_MOVE`
- `KIND_SENSOR`
- `KIND_BEHAVIOR`

Implemented message examples:

- `MOVE_CONTROL_BEGIN_FOR`: starts a control lease.
- `MOVE_BY`: carries forward/back and left/right signed 16-bit directions. Firmware applies a deadzone and maps the command to forward, backward, left turn, right turn, or stop.
- `MOVE_STOP_FOR`: stop/stand command.
- `BEHAVIOR_SIT`: high-level sit request; current firmware maps this to stop/stand.
- `BEHAVIOR_FLIP`: high-level flip request; current firmware logs this over UDP but does not yet start a flip motion.
- `BEHAVIOR_BOW`: high-level bow request; current firmware maps this to bow motion.
- `BEHAVIOR_GIVE_PAW`: high-level paw request; current firmware maps this to paw motion.
- `INFO_ACKNOWLEDGE`: acknowledges a sequence number.
- `SENSOR_DISTANCE`: carries ultrasonic distance in millimeters.

## ⚠️ Current Limitations

- WiFi credentials are still configured in firmware source.
- Behavior messages are mapped to existing safe motions, but sit and UDP-triggered flip still need dedicated calibrated sequences.
- `MOVE_BY` is mapped to basic movement commands, but final live tuning on the physical robot still needs validation.
- The Python controller relies on mDNS/zeroconf discovery rather than a manual IP setting.

## ✅ Debugging Checklist

If WiFi does not work:

- Confirm `PLUTO_ENABLE_WIFI` is defined.
- Confirm credentials are correct.
- Confirm ESP32 and computer are on the same network.
- Confirm mDNS/zeroconf traffic is allowed on the network.
- Confirm UDP port `4242` is not blocked.
- Confirm Python can send packets without socket errors.
- Confirm the ESP32 receives packets by adding temporary serial logs if needed.
- Confirm `message.h` and `message.py` still agree.

## 📚 Related Documentation

- [Shared Communication Protocol](src/comm/README.md)
- [Python Controller](src/control/README.md)
- [ESP32 Firmware](src/esp/README.md)
- [Troubleshooting](TROUBLESHOOTING.md)

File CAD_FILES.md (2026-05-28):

# 🧱 CAD Files

This page documents the CAD/STL files used to physically print Pluto. The printable robot parts are stored separately from the simplified simulation meshes.

<p align="center">
  
</p>

## 🖨️ Physical 3D-Printing Files

Use this folder for fabrication:

```text
src/3D printing mesh/
```

The folder is organized by physical leg position:

| Folder | Purpose |
| --- | --- |
| [Front Left](<src/3D printing mesh/Front Left>) | Printable parts for the front-left leg |
| [Front Right](<src/3D printing mesh/Front Right>) | Printable parts for the front-right leg |
| [Back Left](<src/3D printing mesh/Back Left>) | Printable parts for the back-left leg |
| [Back Right](<src/3D printing mesh/Back Right>) | Printable parts for the back-right leg |

The folder also includes top-level printable files for the main body, board holder, sensor holder, and shared TPU feet:

- [Main Body.stl](<src/3D printing mesh/Main Body.stl>)
- [Board Holder.stl](<src/3D printing mesh/Board Holder.stl>)
- [Sensor Holder.stl](<src/3D printing mesh/Sensor Holder.stl>)
- [TPU Foot.stl](<src/3D printing mesh/TPU Foot.stl>)

Each leg folder contains the printable coxa, femur, tibia, spacer, and linkage/bar parts for that specific leg. `TPU Foot.stl` is shared across the legs and should be printed once per foot.

## 🖨️ Printable Parts By Leg

### 📌 Front Left

- [Front Left COXA.stl](<src/3D printing mesh/Front Left/Front Left COXA.stl>)
- [Front Left Inner FEMUR.stl](<src/3D printing mesh/Front Left/Front Left Inner FEMUR.stl>)
- [Front Left Outer FEMUR.stl](<src/3D printing mesh/Front Left/Front Left Outer FEMUR.stl>)
- [Front Left Spacer FEMUR.stl](<src/3D printing mesh/Front Left/Front Left Spacer FEMUR.stl>)
- [Front Left TIBIA.stl](<src/3D printing mesh/Front Left/Front Left TIBIA.stl>)
- [Front Left Inner Mirror TIBIA.stl](<src/3D printing mesh/Front Left/Front Left Inner Mirror TIBIA.stl>)
- [Front Left Bar.stl](<src/3D printing mesh/Front Left/Front Left Bar.stl>)

### 📌 Front Right

- [Front Right COXA.stl](<src/3D printing mesh/Front Right/Front Right COXA.stl>)
- [Front Right Inner FEMUR.stl](<src/3D printing mesh/Front Right/Front Right Inner FEMUR.stl>)
- [Front Right Outer FEMUR.stl](<src/3D printing mesh/Front Right/Front Right Outer FEMUR.stl>)
- [Front Right Spacer FEMUR.stl](<src/3D printing mesh/Front Right/Front Right Spacer FEMUR.stl>)
- [Front Right Inner TIBIA.stl](<src/3D printing mesh/Front Right/Front Right Inner TIBIA.stl>)
- [Front Right Inner Mirror TIBIA.stl](<src/3D printing mesh/Front Right/Front Right Inner Mirror TIBIA.stl>)
- [Front Right Bar.stl](<src/3D printing mesh/Front Right/Front Right Bar.stl>)

### 📌 Back Left

- [Back Left COXA.stl](<src/3D printing mesh/Back Left/Back Left COXA.stl>)
- [Back Left Inner FEMUR.stl](<src/3D printing mesh/Back Left/Back Left Inner FEMUR.stl>)
- [Back Left Outer FEMUR.stl](<src/3D printing mesh/Back Left/Back Left Outer FEMUR.stl>)
- [Back Left Spacer FEMUR.stl](<src/3D printing mesh/Back Left/Back Left Spacer FEMUR.stl>)
- [Back Left Inner TIBIA.stl](<src/3D printing mesh/Back Left/Back Left Inner TIBIA.stl>)
- [Back Left Inner Mirror TIBIA.stl](<src/3D printing mesh/Back Left/Back Left Inner Mirror TIBIA.stl>)
- [Back Left Bar.stl](<src/3D printing mesh/Back Left/Back Left Bar.stl>)

### 📌 Back Right

- [Back Right COXA.stl](<src/3D printing mesh/Back Right/Back Right COXA.stl>)
- [Back Right Inner FEMUR.stl](<src/3D printing mesh/Back Right/Back Right Inner FEMUR.stl>)
- [Back Right Outer FEMUR.stl](<src/3D printing mesh/Back Right/Back Right Outer FEMUR.stl>)
- [Back Right Spacer FEMUR.stl](<src/3D printing mesh/Back Right/Back Right Spacer FEMUR.stl>)
- [Back Right Inner TIBIA.stl](<src/3D printing mesh/Back Right/Back Right Inner TIBIA.stl>)
- [Back Right Inner Mirror TIBIA.stl](<src/3D printing mesh/Back Right/Back Right Inner Mirror TIBIA.stl>)
- [Back Right Bar.stl](<src/3D printing mesh/Back Right/Back Right Bar.stl>)

## 🧰 How To Use These Files From Scratch

1. Print one complete leg folder first, preferably the leg you will use for test fitting.
2. Assemble that one leg before printing all remaining parts.
3. Check servo fit, screw holes, bearing fit, spacer alignment, and linkage motion.
4. Label every printed part by leg position immediately after printing.
5. Do not mix front/back or left/right parts.
6. After mechanical assembly, verify that the physical leg positions match the firmware leg names in `src/esp/legs/leg_data.h`.

The printed parts and firmware calibration are connected. If a leg is mounted on the wrong side, the calibration values and servo channel mapping may no longer match the physical robot.

## 🧱 Simulation Meshes

Simulation-specific meshes are stored in:

```text
src/sim/sim_mesh/
```

These files are not the primary physical printing files. They are simplified/organized for simulation use and include:

- `body.stl`
- `tl_coxa.stl`, `tl_femur.stl`, `tl_tibia.stl`
- `tr_coxa.stl`, `tr_femur.stl`, `tr_tibia.stl`
- `bl_coxa.stl`, `bl_femur.stl`, `bl_tibia.stl`
- `br_coxa.stl`, `br_femur.stl`, `br_tibia.stl`
- `pluto.xml`

The MuJoCo model is [src/sim/sim_mesh/pluto.xml](src/sim/sim_mesh/pluto.xml).

See [SIMULATION.md](SIMULATION.md) for the current simulation split.

## 📝 Printing Notes

- Print rigid structural parts in PLA or PETG.
- Print [TPU Foot.stl](<src/3D printing mesh/TPU Foot.stl>) in TPU or another flexible material for foot contact.
- Print and inspect one full leg before printing the entire set.
- Keep track of front/back and left/right orientation during assembly.
- Check bearing fits, screw holes, servo horn alignment, and linkage movement before final assembly.

## 🖨️ Recommended Print Validation

Before committing to the full robot:

- Confirm that the servo body fits without forcing the print.
- Confirm that the servo horn can be mounted without rubbing.
- Confirm that the tibia bearing sits flat.
- Confirm that screw holes can be used without cracking the part.
- Confirm that leg movement is smooth before electronics are powered.

## 📚 Related Documentation

- [Assembly Instructions](ASSEMBLY.md)
- [Wiring & Electrical](WIRING_ELECTRICAL.md)
- [Hardware Overview](HARDWARE_OVERVIEW.md)
- [Simulation Notes](SIMULATION.md)

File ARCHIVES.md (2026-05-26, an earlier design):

# 🗄️ Archives

This repository does not currently contain a dedicated `archives/` directory.

The purpose of a future archive directory would be to preserve previous prototypes, tests, and implementations that are no longer part of the active Pluto codebase, while keeping them available for reference.

## 📌 What Should Be Archived

Use an archive folder for work that is useful historically but should not be part of the active runtime path:

- early gait experiments that were replaced by the current gait controller
- old inverse-kinematics prototypes
- temporary servo calibration sketches
- sensor bring-up tests
- older PyBullet or MuJoCo experiments
- communication protocol experiments that were replaced by the current UDP packet format
- hardware test scripts that require outdated wiring or assumptions

## 🗂️ Suggested Structure

If archives are added later, use a structure like:

```text
archives/
|-- esp/
|   |-- gait_tests/
|   |-- servo_calibration/
|   `-- sensor_tests/
|-- control/
|   |-- simulation_tests/
|   `-- ui_prototypes/
`-- comm/
    `-- protocol_experiments/
```

Each archived subdirectory should include a short `README.md` explaining:

- what was tested
- why it is no longer active
- whether it still runs
- which current implementation replaced it

## 🧪 Current Active Test References

At the moment, first-time validation is documented through:

- [README.md](README.md): quick start, firmware flashing, and setup flow
- [TROUBLESHOOTING.md](TROUBLESHOOTING.md): first-time setup issues
- [ONGOING_WORK.md](ONGOING_WORK.md): known limitations and planned improvements
- [SIMULATION.md](SIMULATION.md): current simulation split and known limitations
- [src/esp/main.cpp](src/esp/main.cpp): serial commands for early gait and servo testing

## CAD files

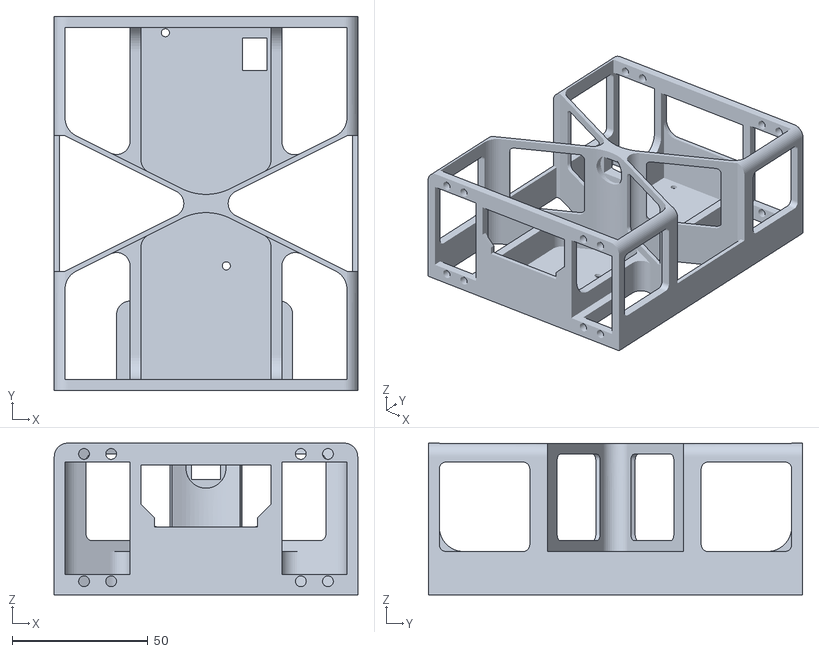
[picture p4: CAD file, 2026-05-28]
src/3D printing mesh/Main Body.stl
112.0 x 138.0 x 56.0

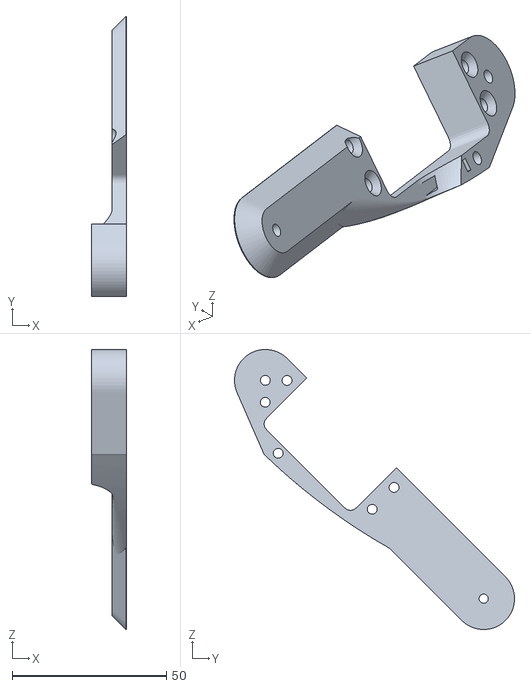
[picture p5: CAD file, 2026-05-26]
src/3D printing mesh/Back Left/Back Left Inner FEMUR.stl
11.4 x 90.7 x 90.7

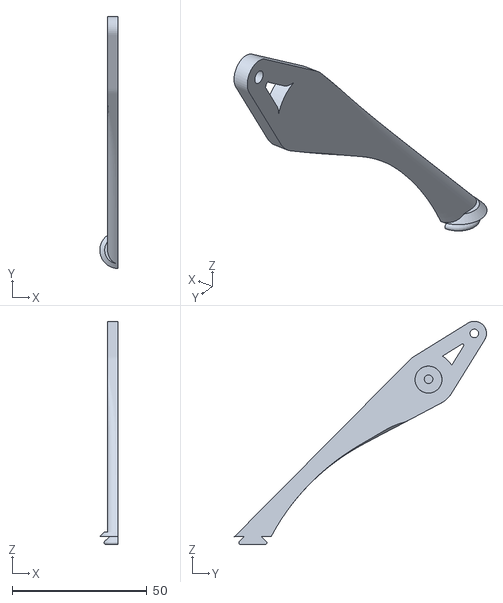
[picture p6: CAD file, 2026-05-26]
src/3D printing mesh/Back Right/Back Right Inner TIBIA.stl
6.78 x 93.4 x 82.8

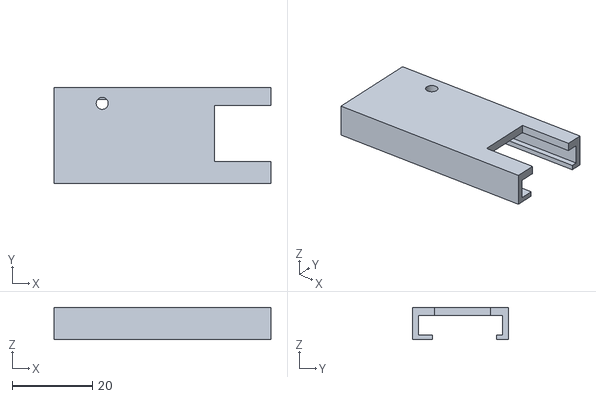
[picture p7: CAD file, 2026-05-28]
src/3D printing mesh/Board Holder.stl
54.0 x 24.0 x 8.00

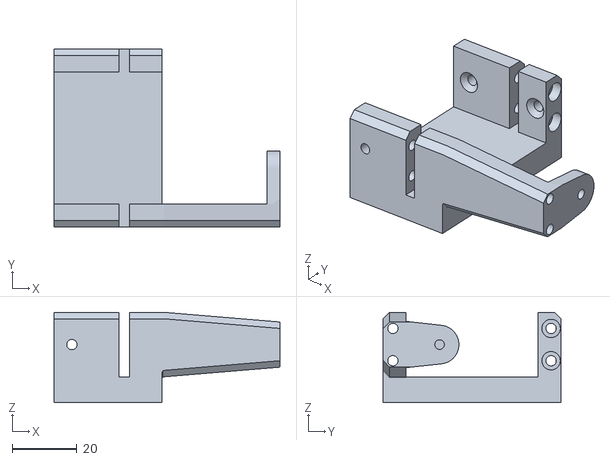
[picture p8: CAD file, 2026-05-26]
src/3D printing mesh/Front Left/Front Left COXA.stl
70.0 x 55.0 x 28.0

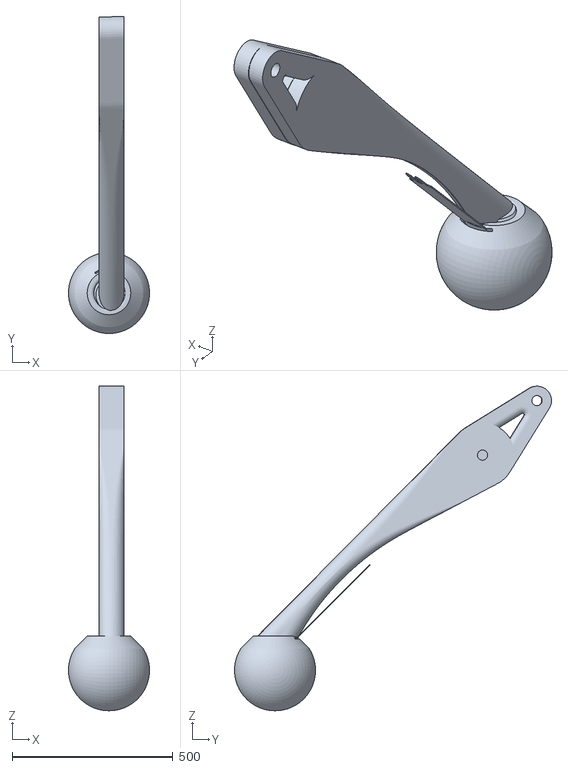
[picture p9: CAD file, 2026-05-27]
src/sim/sim_mesh/tl_tibia.stl
252.4 x 986.9 x 1010.7

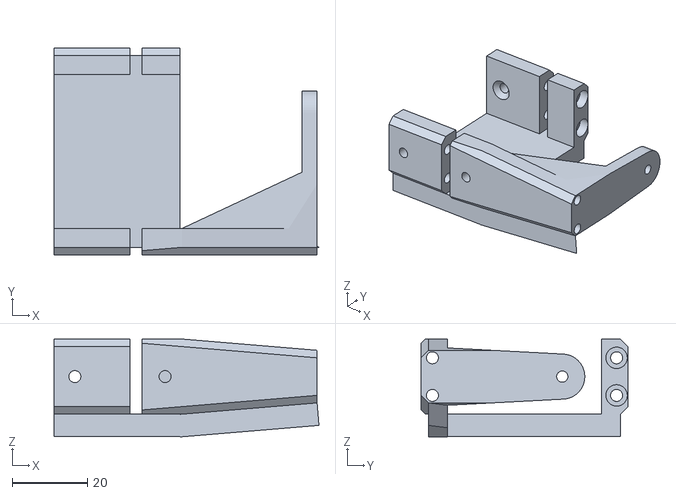
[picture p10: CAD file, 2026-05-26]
src/3D printing mesh/Back Left/Back Left COXA.stl
70.5 x 55.0 x 26.1

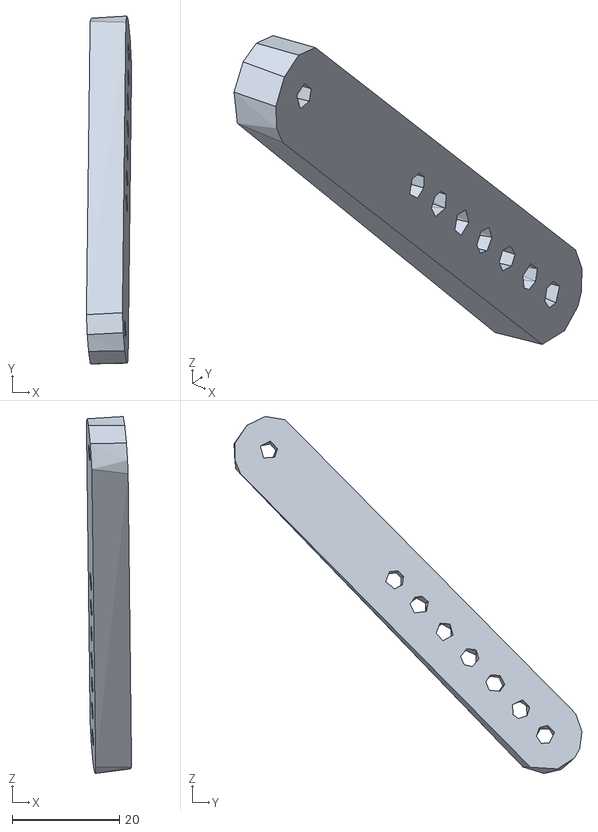
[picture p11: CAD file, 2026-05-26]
src/3D printing mesh/Front Left/Front Left Bar.stl
8.42 x 64.8 x 66.5

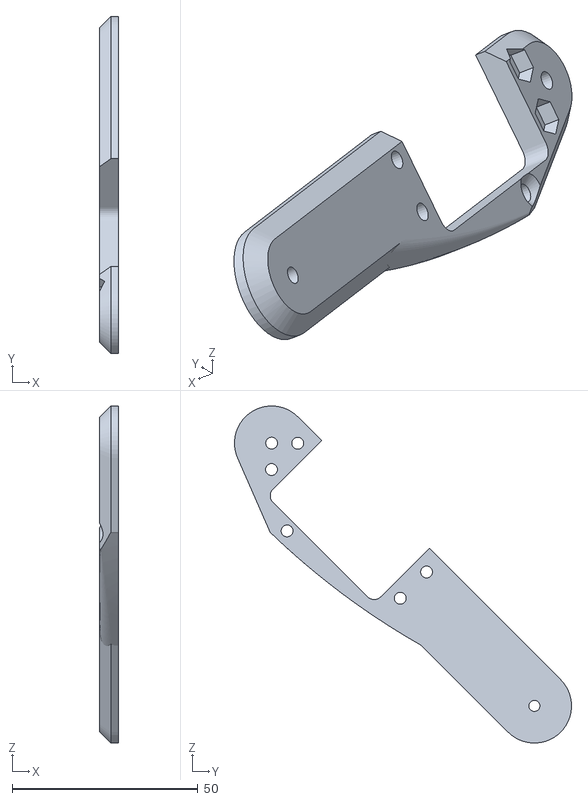
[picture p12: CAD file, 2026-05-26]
src/3D printing mesh/Front Right/Front Right Outer FEMUR.stl
5.00 x 90.7 x 90.7

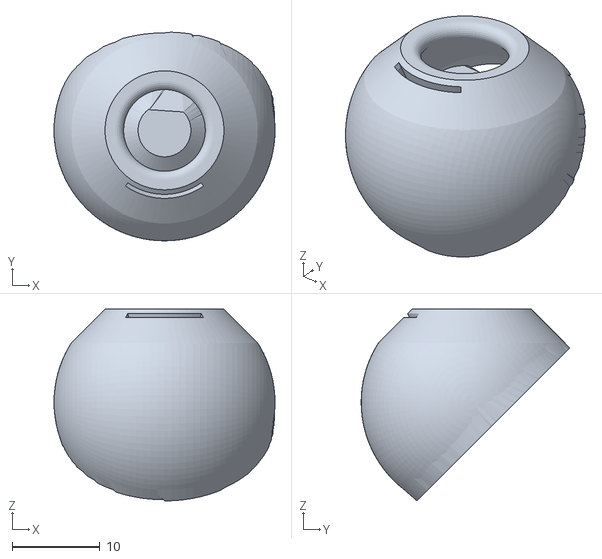
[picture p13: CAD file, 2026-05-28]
src/3D printing mesh/TPU Foot.stl
25.2 x 23.8 x 21.9

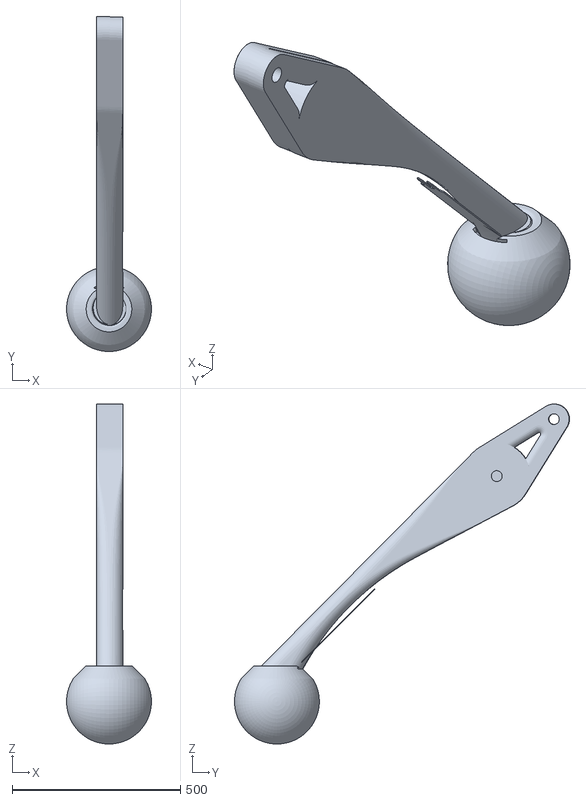
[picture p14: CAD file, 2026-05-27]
src/sim/sim_mesh/br_tibia.stl
252.4 x 996.0 x 1010.7

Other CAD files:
src/3D printing mesh/Front Right/Front Right Inner TIBIA.stl
src/3D printing mesh/Back Right/Back Right Inner Mirror TIBIA.stl
src/3D printing mesh/Front Right/Front Right COXA.stl
src/sim/sim_mesh/tr_tibia.stl
src/3D printing mesh/Back Left/Back Left Bar.stl
src/3D printing mesh/Back Right/Back Right Bar.stl
src/3D printing mesh/Front Left/Front Left Inner Mirror TIBIA.stl
src/3D printing mesh/Back Left/Back Left Inner Mirror TIBIA.stl
src/3D printing mesh/Back Left/Back Left Inner TIBIA.stl
src/3D printing mesh/Back Left/Back Left Outer FEMUR.stl
src/3D printing mesh/Back Left/Back Left Spacer FEMUR.stl
src/3D printing mesh/Back Right/Back Right COXA.stl
src/3D printing mesh/Back Right/Back Right Inner FEMUR.stl
src/3D printing mesh/Back Right/Back Right Outer FEMUR.stl
src/3D printing mesh/Back Right/Back Right Spacer FEMUR.stl
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

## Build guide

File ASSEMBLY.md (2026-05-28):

# 🧩 Assembly Instructions

Follow these steps to assemble Pluto. Read [Wiring & Electrical](WIRING_ELECTRICAL.md) before powering anything.

## 🎯 Build Philosophy

This guide assumes a future team is building Pluto from scratch. Build and test one layer at a time:

1. Print and inspect the mechanical parts.
2. Assemble one leg and verify that all joints move freely by hand.
3. Assemble the remaining legs only after the first leg is understood.
4. Mount electronics without connecting the battery yet.
5. Build and verify the power system with a multimeter.
6. Flash firmware over USB before using battery power.
7. Test individual joints before testing full gaits.

Do not skip directly to walking. Most failures in quadruped builds come from reversed servo orientation, incorrect power wiring, missing common ground, or uncalibrated joint limits.

## 📋 Required Inputs Before Starting

| Item | Source |
| --- | --- |
| Printed body and leg meshes | [CAD_FILES.md](CAD_FILES.md), `src/3D printing mesh/` |
| Wiring plan | [WIRING_ELECTRICAL.md](WIRING_ELECTRICAL.md) |
| Firmware setup | [src/esp/README.md](src/esp/README.md) |
| Servo calibration file | `src/esp/legs/leg_data.h` |
| Troubleshooting checklist | [TROUBLESHOOTING.md](TROUBLESHOOTING.md) |

## 🧭 Mechanical Orientation

The code uses four leg positions:

| Firmware name | Physical meaning |
| --- | --- |
| `TOP_LEFT` | Forward-facing left leg |
| `TOP_RIGHT` | Forward-facing right leg |
| `BOTTOM_LEFT` | Rear-facing left leg |
| `BOTTOM_RIGHT` | Rear-facing right leg |

The mesh filenames use the same idea:

- `tl_*`: top-left leg parts.
- `tr_*`: top-right leg parts.
- `bl_*`: bottom-left leg parts.
- `br_*`: bottom-right leg parts.

Keep this orientation consistent while assembling, wiring, and calibrating. If a leg is physically swapped, the servo channel mapping and calibration values will no longer match the robot.

## 🖨️ 1. Print Parts

Print the required body and leg parts from the current physical mesh set in [src/3D printing mesh](<src/3D printing mesh>). The active mesh inventory is documented in [CAD_FILES.md](CAD_FILES.md).

<p align="center">
  Full body CAD model of Pluto
</p>

Current physical print groups:

- Top-level body/electronics/foot parts: `Main Body.stl`, `Board Holder.stl`, `Sensor Holder.stl`, `TPU Foot.stl`
- Front-left leg folder: coxa, inner/outer femur, femur spacer, tibia, inner mirror tibia, and linkage bar
- Front-right leg folder: coxa, inner/outer femur, femur spacer, inner tibia, inner mirror tibia, and linkage bar
- Back-left leg folder: coxa, inner/outer femur, femur spacer, inner tibia, inner mirror tibia, and linkage bar
- Back-right leg folder: coxa, inner/outer femur, femur spacer, inner tibia, inner mirror tibia, and linkage bar

The MuJoCo-style names such as `body.stl`, `tl_coxa.stl`, and `br_tibia.stl` are simulation meshes under `src/sim/sim_mesh/`, not the main physical printing inventory.

Print rigid body and leg parts in PLA or PETG. Print `TPU Foot.stl` in TPU or another flexible material.

## ⚡ 2. Prepare Electronics

Before installing electronics in the body:

1. Adjust the LM2596 buck converter output with a multimeter.
2. Confirm LiPo polarity and XT60 wiring.
3. Confirm the PCA9685 logic and servo power paths.
4. Confirm all grounds will be connected together.
5. Check the ultrasonic ECHO voltage level before connecting it to an ESP32 GPIO.

Full wiring guide: [WIRING_ELECTRICAL.md](WIRING_ELECTRICAL.md)

## 🧩 3. Assemble Legs

Each leg has three main sections:

- Coxa: hip joint.
- Femur: upper leg.
- Tibia: lower leg.

Each leg requires:

- 3 servos.
- 3 servo horns or servo arms.
- M3 screws for most mechanical connections.
- Bearings and linkage hardware for the tibia mechanism.
- Printed `TPU Foot.stl` part or a rubber pad substitute.

### 🧩 Step 1: Assemble the Tibia

- Take the two tibia printed parts.
- Insert a ball bearing between both parts.
- Align the pieces and screw them together.
- Glue or fasten the printed TPU foot to the lower end.

<p>
  Tibia assembly photo 1
  Tibia assembly photo 2
  Tibia assembly photo 3
</p>

### 🧩 Step 2: Assemble the Femur

- Take the femur inner part, spacer, and outer part.
- Place the servo between the femur sides.
- Stack the three parts around the servo.
- Add adjacent screws to reinforce the structure and improve stability.

<p>
  Femur assembly photo 1
  Femur assembly photo 2
</p>

### 🧩 Step 3: Assemble the Coxa

- Take the coxa printed part for the selected leg.
- Insert the screw from the correct side for that leg's geometry.
- Attach the coxa to the servo horn mounted on the body.
- Mount the coxa servo and check that the open sections are aligned.

### 📌 Step 4: Attach the Femur to the Coxa

- Take the assembled femur.
- Align the highest hole on the femur outer part with the coxa servo horn.
- Secure the connection using an M3x35 screw.

<p>
  Femur-to-coxa assembly photo
</p>

### 📌 Step 5: Attach the Tibia to the Femur

- Attach the printed linkage bar to the femur servo horn using the side with the single hole.
- Connect the opposite side of the linkage bar to the upper tibia part.
- Choose the linkage hole position based on the desired bend:
  - Holes closer to the center create a smaller bending angle.
- Holes farther away create a larger bending angle.

<p>
  Tibia-to-femur linkage photo
</p>

### 📌 Step 6: Repeat for All Legs

Repeat the previous steps for each leg. Check:

- Servo orientation.
- Screw tightness.
- Smooth joint movement.
- Correct linkage alignment.
- No mechanical blocking across the expected range.

<p>
  Leg assembly photo 1
  Leg assembly photo 2
</p>

## 🧩 4. Assemble the Body

Use M3 screws unless a part requires a different size. Coxa servos use M2.5 screws.

1. Screw the coxa servo motors onto the body.
2. Mount the PCA9685 servo driver.
3. Mount the buck converter.
4. Slide the ultrasonic sensor into its holder and secure it.
5. Slide the protection board into its holder and secure it.
6. Attach the LiPo with Velcro or another removable mount.
7. Mount the microphone if used.
8. Slide or mount the ESP32 into the body.

Reference images:

<p>
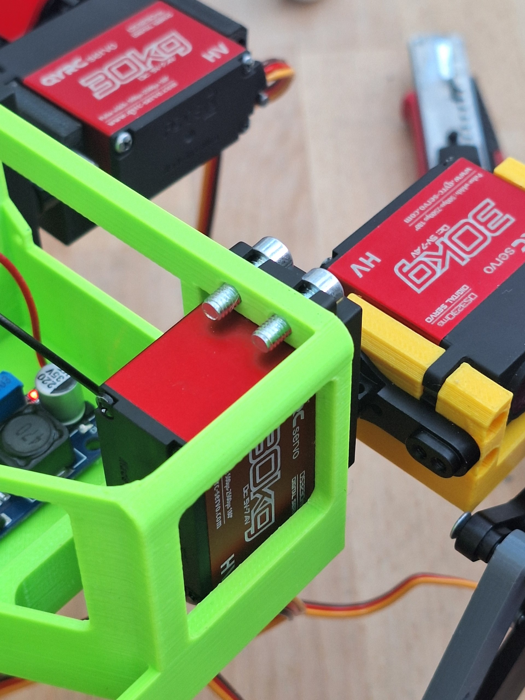
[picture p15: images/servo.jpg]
Servo mounted in body
  
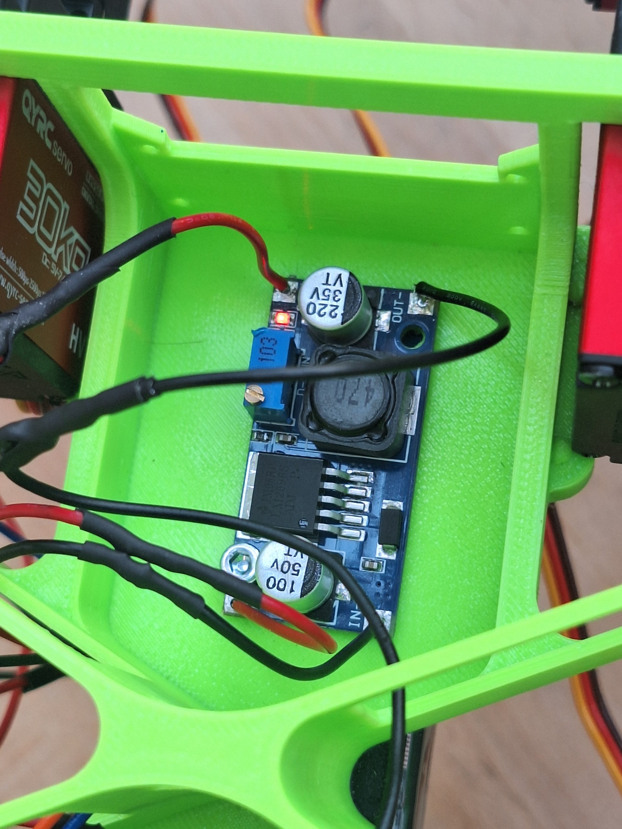
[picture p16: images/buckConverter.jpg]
Buck converter mounted in body
  
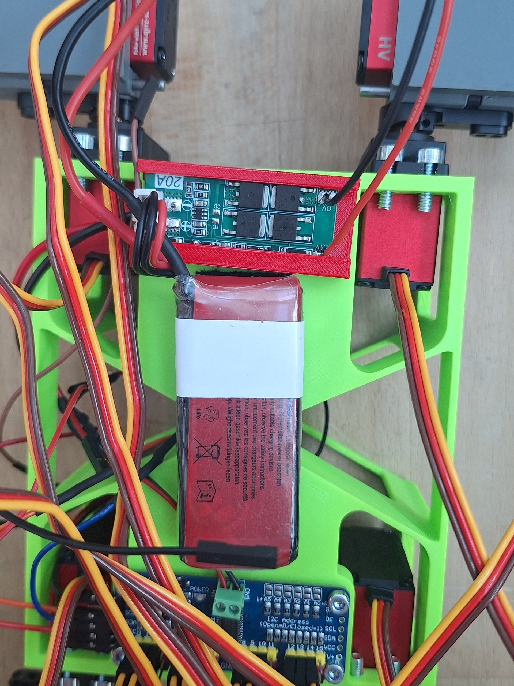
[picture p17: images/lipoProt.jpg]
LiPo protection and battery mounting
  
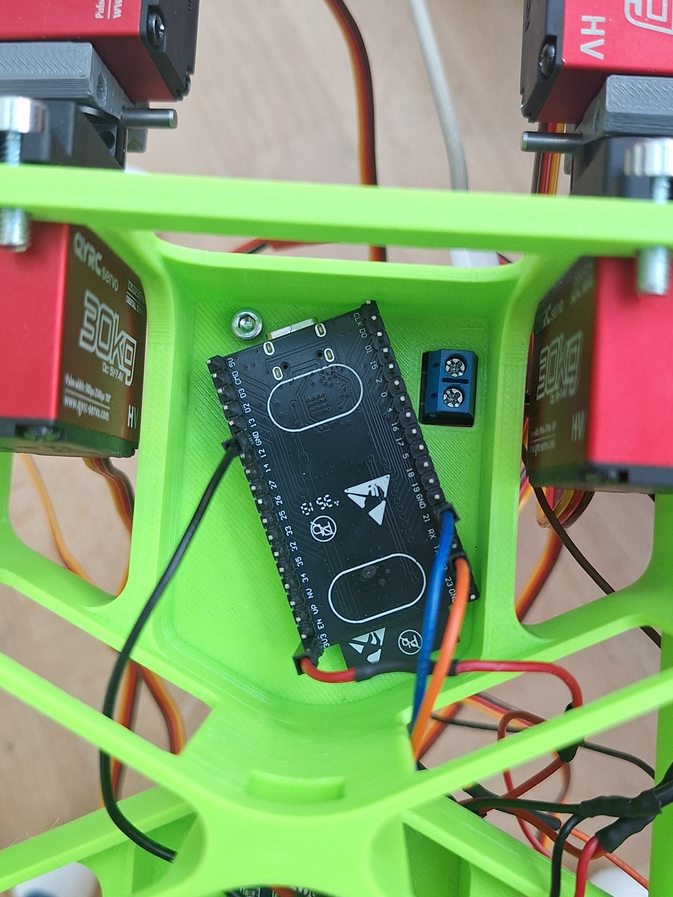
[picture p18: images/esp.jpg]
ESP32 mounted in body
  
</p>

## 📌 5. Wire and Test

1. Plug all cables according to [WIRING_ELECTRICAL.md](WIRING_ELECTRICAL.md).
2. Check polarity and continuity with a multimeter.
3. Flash the ESP32 firmware.
4. Open the serial monitor at `115200`.
5. Test stand, stop, and small trimming commands before walking.
6. Tune servo calibration in `src/esp/legs/leg_data.h`.

## 🧩 Bring-Up Sequence After Assembly

Use this order after the robot is mechanically assembled:

1. Power the ESP32 from USB only.
2. Build and upload the firmware with `pio run -t upload`.
3. Open the serial monitor with `pio device monitor -b 115200`.
4. Confirm that the firmware prints the command list.
5. Power the PCA9685 logic side and confirm it initializes.
6. Connect only one servo or one leg for first motion tests if possible.
7. Use `l` and `n` to select leg and joint, then `+`, `-`, `r`, and `p` for small trimming checks.
8. Confirm that increasing/decreasing pulse values moves the expected joint.
9. Update `src/esp/legs/leg_data.h` if a joint direction, start pulse, or safe range is wrong.
10. Repeat for all joints before running walking commands.

## ✅ Completion Checklist

The hardware build is not complete until all checks pass:

- All screws are tight but joints still move freely.
- No wire can be caught by a moving leg.
- Battery is mounted securely and can be disconnected quickly.
- Buck converter output has been measured.
- ESP32, PCA9685, sensors, and servo power share ground.
- Each servo channel moves the expected joint.
- Servo calibration limits prevent mechanical over-travel.
- `s` returns the robot to stop/stand behavior.

Software instructions: [SOFTWARE_OVERVIEW.md](SOFTWARE_OVERVIEW.md)

Troubleshooting: [TROUBLESHOOTING.md](TROUBLESHOOTING.md)

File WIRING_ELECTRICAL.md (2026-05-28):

# 🔌 Wiring & Electrical

This page summarizes Pluto's wiring and electrical setup. For the physical assembly sequence, see [Assembly Instructions](ASSEMBLY.md).

## 🔌 Circuit Diagram

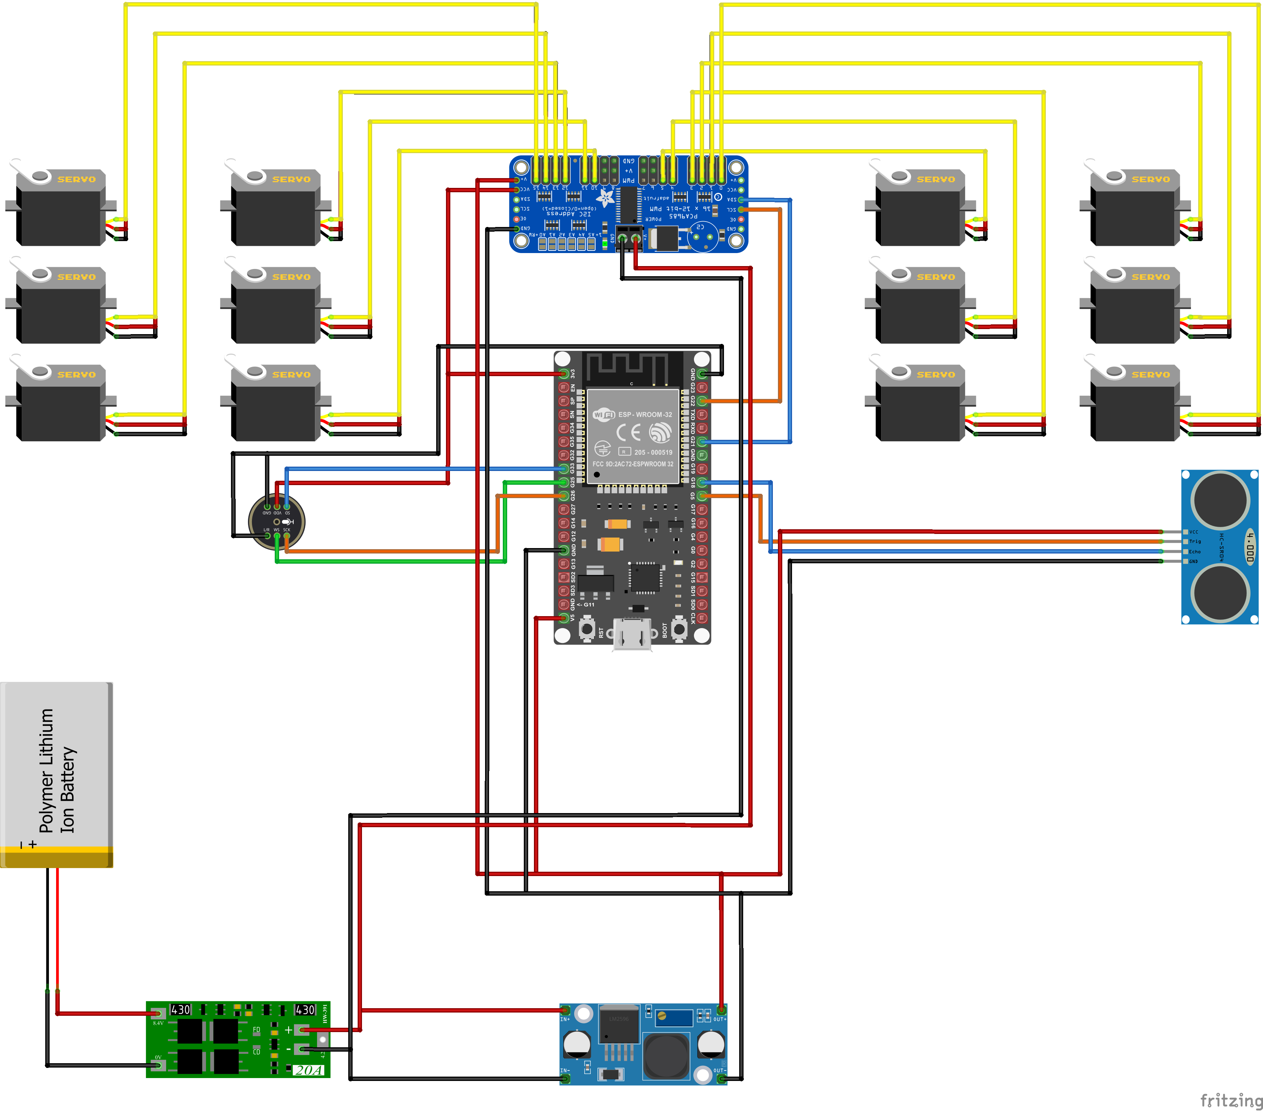
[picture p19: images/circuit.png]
Circuit Diagram


Use this diagram as the reference for the current wiring layout, then verify every connection against the actual hardware before powering the robot.

## 🔋 Power Path

Pluto uses a 7.4V 2S LiPo battery as the main power source.

Typical power path:

```text
7.4V 2S LiPo
  -> XT60 connector
  -> KCD1 rocker switch
  -> servo power rail / PCA9685 servo power
  -> LM2596 buck converter
  -> ESP32 and low-voltage electronics
```

Important checks:

- Use thick wires for high-current servo power.
- Confirm LiPo polarity before plugging in the battery.
- Adjust and verify the LM2596 output voltage with a multimeter before connecting the ESP32.
- Connect all grounds together: LiPo/servo ground, PCA9685 ground, ESP32 ground, buck converter ground, and sensor ground.
- Do not test full gaits until standing poses and single-leg motion are stable.

## 🧰 Wiring Order From Scratch

Wire the robot in this order. Each step should be verified before continuing:

1. Battery connector and rocker switch.
2. Servo power rail and PCA9685 servo power input.
3. Buck converter input from the switched battery side.
4. Buck converter output, measured before connecting electronics.
5. ESP32 regulated power and ground.
6. PCA9685 logic power, ground, SDA, and SCL.
7. One servo channel for initial testing.
8. Remaining servo channels after the first channel works.
9. Ultrasonic sensor power, ground, trigger, and echo.
10. Microphone I2S power, ground, and signal pins.

If a later step fails, disconnect power and return to the last verified step.

## 📶 ESP32 Connections

The ESP32 is the main controller. It handles firmware execution, sensor reads, serial debugging, WiFi/UDP, and communication with the PCA9685 servo driver.

Check these before powering the full robot:

- ESP32 is connected over USB for flashing and serial monitoring.
- ESP32 receives a safe regulated voltage from the buck converter when running from battery.
- ESP32 and PCA9685 share I2C SDA/SCL and common ground.
- Sensor pins match the templates in `src/esp/main.cpp`.
- WiFi credentials are configured in `src/esp/main.cpp` only if `PLUTO_ENABLE_WIFI` is enabled.

## 🔌 PCA9685 and Servo Wiring

The PCA9685 drives all 12 servos.

- Connect PCA9685 logic power to the ESP32-compatible logic supply.
- Connect PCA9685 servo power to the servo power rail.
- Keep servo power wiring short and thick enough for current spikes.
- Connect each servo to the expected PCA9685 channel before calibration.
- Check servo orientation mechanically before sending large movements.

## 🎚️ Servo Channel Mapping

The firmware assigns channels from `src/esp/legs/leg.h`. Each leg uses four channel slots, but only the first three are used for coxa, femur, and tibia.

| Leg | Coxa channel | Femur channel | Tibia channel | Unused slot |
| --- | ---: | ---: | ---: | ---: |
| `TOP_LEFT` | 0 | 1 | 2 | 3 |
| `TOP_RIGHT` | 4 | 5 | 6 | 7 |
| `BOTTOM_LEFT` | 8 | 9 | 10 | 11 |
| `BOTTOM_RIGHT` | 12 | 13 | 14 | 15 |

Before running gait commands, verify that each physical servo is plugged into the channel expected by this table. If a servo is on the wrong channel, the IK and gait code will move the wrong joint.

## 📡 Sensors

Current sensor notes:

- Ultrasonic sensor: HC-SR04-style sensor, mounted at the front of the robot.
- Microphone: INMP441 I2S microphone, mounted near the top-middle of the body.

Current firmware pin templates:

- Ultrasonic sensor: `SensorUltraSonic<5, 18>`
- Microphone: `SensorMicrophone<26, 25, 33>`

If the ultrasonic ECHO line outputs 5V, use a voltage divider or level shifter before connecting it to an ESP32 GPIO.

See [SOFTWARE_SENSORS.md](SOFTWARE_SENSORS.md) for software-side sensor behavior.

## 🧪 Minimum Electrical Tests

Before full robot testing:

1. With battery disconnected, check continuity for ground paths.
2. With servos disconnected, power the logic electronics and verify ESP32 startup.
3. Confirm the PCA9685 is detected by firmware and receives logic power.
4. Connect one servo and test small raw changes from the serial monitor.
5. Connect the remaining servos only after the first servo behaves correctly.
6. Test the ultrasonic sensor separately before relying on wall-stop behavior.
7. If clap-toggle behavior is re-enabled in firmware, test microphone energy readings before relying on it.

## ✅ First Power-Up Checklist

1. Inspect solder joints and connector polarity.
2. Check for shorts with a multimeter.
3. Verify the buck converter output before connecting low-voltage electronics.
4. Connect the ESP32 over USB and confirm firmware upload/serial monitor works.
5. Connect the LiPo through XT60.
6. Turn on the rocker switch.
7. Confirm ESP32, PCA9685, sensors, and servos power up normally.
8. Test simple serial commands before running full locomotion.

If something behaves unexpectedly, turn the robot off and see [First-Time Troubleshooting](TROUBLESHOOTING.md).

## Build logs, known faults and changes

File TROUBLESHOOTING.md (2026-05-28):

# 🛠️ First-Time Troubleshooting

Use this guide when Pluto does not start cleanly. Start with the section that matches the symptom.

## 🛠️ Debugging Rule For A New Build

When building from scratch, debug in this order:

1. Mechanical binding.
2. Power and ground.
3. ESP32 flashing and serial output.
4. PCA9685 and one servo.
5. All servo channel mapping.
6. Servo calibration.
7. Sensors.
8. WiFi.
9. Controller UI.
10. Gait behavior.

Do not debug gait behavior before power, wiring, and calibration are known to be correct.

## 🎛️ Controller UI Does Not Start

### 📌 Python 3.13 Not Found

The run scripts require Python 3.13.

Check your version:

```bash
python3 --version
```

On Windows:

```cmd
py -3.13 --version
```

If Python 3.13 is missing, install it from <https://www.python.org/downloads/> and run the script again.

### 📦 Dependencies Did Not Install Correctly

Force a clean reinstall:

```bash
bash run.sh --reinstall
```

On Windows:

```cmd
run.bat --reinstall
```

This recreates `.venv` and reinstalls `requirements.txt`.

### 📌 Port 8090 Is Already In Use

Run the UI on another port:

```bash
bash run.sh --port 8081
```

On Windows:

```cmd
run.bat --port 8081
```

Then open `http://localhost:8081`.

## 🎮 Simulation Does Not Open

### 🎮 PyBullet UI

- Make sure you are running on a machine with a desktop display.
- If running over SSH or in a headless environment, PyBullet GUI mode may not open.
- Check that `pybullet` installed successfully in `.venv`.
- Try `bash run.sh --reinstall` if the package installation looks incomplete.
- Current limitation: `src/control/sim_motion.py` still references old generic visual mesh files. See [SIMULATION.md](SIMULATION.md).

### 🎮 MuJoCo Bridge

- Confirm a local MuJoCo installation is available and pass it to CMake with `-DMUJOCO_DIR=...`.
- Confirm that [src/sim/sim_mesh/pluto.xml](src/sim/sim_mesh/pluto.xml) can find the STL files in `src/sim/sim_mesh`.
- The C++ MuJoCo bridge under `src/sim` is built with the top-level `CMakeLists.txt`, not the ESP32 PlatformIO firmware build.

See [SIMULATION.md](SIMULATION.md).

## 🧠 ESP32 Firmware Does Not Build Or Upload

### 📌 PlatformIO Is Missing

Install PlatformIO Core or use the PlatformIO VS Code extension.

Check:

```bash
pio --version
```

### 📌 Upload Port Is Not Detected

List connected devices:

```bash
pio device list
```

Upload with an explicit port:

```bash
pio run -t upload --upload-port /dev/cu.usbserial-XXXX
```

On Windows, the port usually looks like `COM3`, `COM4`, etc.

```cmd
pio run -t upload --upload-port COM3
```

### ⌨️ Serial Monitor Shows Nothing

Use the configured baud rate:

```bash
pio device monitor -b 115200
```

If the monitor still shows nothing, check the USB cable, board selection, and whether the ESP32 is powered.

## 📶 Robot Does Not Connect Over WiFi

WiFi is implemented and currently enabled in `src/esp/main.cpp`, but it still needs valid credentials and local-network discovery.

Check:

- `#define PLUTO_ENABLE_WIFI` is enabled.
- The WiFi network is added in `setup()` with `PLUTO_SERVER.addAP(<WIFI_NAME>, <WIFI_PASSWORD>)`.
- The computer and ESP32 are on the same network.
- The ESP32 serial monitor shows WiFi startup activity.
- mDNS/zeroconf traffic is allowed so the controller can find `_pluto._udp.local`.
- UDP port `4242` is not blocked by the network or firewall.

For packet details, see [SOFTWARE_WIFI.md](SOFTWARE_WIFI.md).

## 🔩 Hardware Powers On But Servos Do Not Move

- Verify the PCA9685 is powered and connected to the ESP32 I2C lines.
- Check that servo power and logic ground share a common ground.
- Confirm the LiPo is charged and the rocker switch is on.
- Check that the servos are connected to the expected PCA9685 channels.
- Use the serial monitor to test simple firmware commands before trying full walking.
- Check `src/esp/legs/leg_data.h` for calibration limits and motion-specific starting pulses.

Do not continue testing if a servo stalls, overheats, chatters heavily, or pulls the robot into a mechanically blocked position.

## 📌 Robot Resets Or Behaves Unstable

This is often a power issue.

- Check the LiPo charge level.
- Verify the buck converter output before connecting sensitive electronics.
- Use thick enough wires for servo power.
- Confirm XT60 and switch connections are secure.
- Confirm all grounds are connected together.
- Avoid testing full gaits until single-leg and standing poses are stable.

## 📡 Sensors Do Not Respond

- Check the sensor wiring against [SOFTWARE_SENSORS.md](SOFTWARE_SENSORS.md).
- Verify the firmware pin templates:
  - Ultrasonic sensor: `SensorUltraSonic<5, 18>`
  - Microphone: `SensorMicrophone<26, 25, 33>`
- Confirm the sensors share ground with the ESP32.
- Use serial output to inspect raw readings before relying on reactive behavior.
- If the ultrasonic ECHO line is 5V, use a voltage divider or level shifter.

## 🗣️ Speech Commands Do Not Work

Speech recognition runs on the controller computer, not on the ESP32.

- Make sure a microphone is connected and allowed by the operating system.
- Check that `sounddevice` and `vosk` installed correctly.
- Run the controller from a normal desktop session, not a restricted terminal.
- Connect to the robot before expecting speech commands to be sent.
- Speak one of the supported commands clearly, such as `pluto stop`, `pluto sit`, or `pluto give paw`.

## 🆘 Still Stuck

Check these docs next:

- [README.md](README.md)
- [ASSEMBLY.md](ASSEMBLY.md)
- [WIRING_ELECTRICAL.md](WIRING_ELECTRICAL.md)
- [SOFTWARE_WIFI.md](SOFTWARE_WIFI.md)
- [SOFTWARE_SENSORS.md](SOFTWARE_SENSORS.md)
- [SIMULATION.md](SIMULATION.md)
- [ONGOING_WORK.md](ONGOING_WORK.md)

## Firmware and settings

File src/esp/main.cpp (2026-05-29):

#define PLUTO_ENABLE_WIFI
#define PLUTO_ENABLE_ULTRASONIC
// #define PLUTO_ENABLE_MICROPHONE

#include <Arduino.h>
#include <Wire.h>
#include <Adafruit_PWMServoDriver.h>
#include <freertos/FreeRTOS.h>
#include <freertos/task.h>

#include <legs/leg.h>
#include <motion/gait.h>
#include <array>

#ifdef PLUTO_ENABLE_WIFI
  #include <server/server.h>
#endif // PLUTO_ENABLE_WIFI

#ifdef PLUTO_ENABLE_ULTRASONIC
  #include <sensors/ultrasonic.h>
#endif // PLUTO_ENABLE_ULTRASONIC

#ifdef PLUTO_ENABLE_MICROPHONE
  #include <sensors/microphone.h>
#endif // PLUTO_ENABLE_MICROPHONE

#ifdef PLUTO_ENABLE_WIFI
/// @brief The pluto WiFi server
auto PLUTO_SERVER = pluto::PlutoServer{4242};
#endif

pluto::motion::MotionCommand last_wifi_motion = pluto::motion::MotionCommand::IDLE;

/// @brief The PWM driver
Adafruit_PWMServoDriver PWM = Adafruit_PWMServoDriver();
/// @brief The legs
std::array<pluto::Leg, 4> LEGS = {
    pluto::Leg{PWM, pluto::LegSide::TOP_LEFT},
    pluto::Leg{PWM, pluto::LegSide::TOP_RIGHT},
    pluto::Leg{PWM, pluto::LegSide::BOTTOM_LEFT},
    pluto::Leg{PWM, pluto::LegSide::BOTTOM_RIGHT}};

pluto::LegJointType CURRENT_JOINT = pluto::LegJointType::COXA;
pluto::LegSide CURRENT_SIDE       = pluto::LegSide::TOP_LEFT;
pluto::motion::GaitController GAIT;

#ifdef PLUTO_ENABLE_ULTRASONIC
/// @brief Ultrasonic sensor
pluto::SensorUltraSonic<5, 18> SENSOR_ULTRASONIC;
#endif

#ifdef PLUTO_ENABLE_MICROPHONE
/// @brief Microphone sensor
pluto::SensorMicrophone<26, 25, 33> SENSOR_MICROPHONE;
#endif

static bool robot_walking = false;
void stop_robot(const char* reason)
{
  GAIT.set_motion(pluto::motion::MotionCommand::IDLE);
  GAIT.stand(LEGS);
  robot_walking = false;

  Serial.print("STOP: ");
  Serial.println(reason);
}

void start_robot()
{
  GAIT.forward_start(LEGS);
  delay(300);

  GAIT.set_gait(pluto::motion::GaitKind::TROT);
  GAIT.set_speed(0.65F);
  GAIT.set_motion(pluto::motion::MotionCommand::FORWARD);
  robot_walking = true;

  Serial.println("START: robot walking");
}

/**
static constexpr uint32_t CLAP_THRESHOLD = 30000000;
static constexpr uint32_t CLAP_COOLDOWN_MS = 800;
static constexpr uint32_t MICROPHONE_CHECK_PERIOD_MS = 50;
static constexpr uint32_t MICROPHONE_PRINT_PERIOD_MS = 1000; 

void update_microphone_control(uint32_t now)
{
#ifdef PLUTO_ENABLE_MICROPHONE
  static uint32_t last_microphone_check_ms = 0; 
  static uint32_t last_microphone_print_ms = 0; 
  static uint32_t last_clap_ms = 0; 
  static bool was_above_threshold = false; 

  if (now - last_microphone_check_ms < MICROPHONE_CHECK_PERIOD_MS){
    return; 
  }

  last_microphone_check_ms = now; 

  uint32_t mic_energy = SENSOR_MICROPHONE.current_energy(); 

  if (now - last_microphone_print_ms >= MICROPHONE_PRINT_PERIOD_MS)
  {
    last_microphone_print_ms = now; 

    Serial.print("Mic energy: ");
    Serial.println(mic_energy);
  }

  bool above_threshold = mic_energy >= CLAP_THRESHOLD; 

  if (above_threshold && !was_above_threshold && now - last_clap_ms >= CLAP_COOLDOWN_MS)
  {
    last_clap_ms = now; 

    Serial.print("CLAP DETECTED | Energy: "); 
    Serial.println(mic_energy); 
    
    if (robot_walking)
    {
      Serial.println("CLAP ACTION stop robot");
      stop_robot("clap detected");
    }
    else 
    {
      Serial.println("CLAP start robot"); 
      start_robot();
    }
  }

  was_above_threshold = above_threshold; 
#endif
}
*/

static constexpr float WALL_STOP_DISTANCE_CM   = 35.0F;
static constexpr uint32_t ULTRASONIC_PERIOD_MS = 150;
static constexpr uint32_t ULTRASONIC_WAIT_MS   = 10;

void update_ultrasonic_control(uint32_t now)
{
#ifdef PLUTO_ENABLE_ULTRASONIC
  static bool ultrasonic_pending      = false;
  static uint32_t ultrasonic_begin_ms = 0;
  static uint32_t last_ultrasonic_ms  = 0;

  if (!ultrasonic_pending && now - last_ultrasonic_ms >= ULTRASONIC_PERIOD_MS)
  {
    SENSOR_ULTRASONIC.read_begin();
    ultrasonic_pending  = true;
    ultrasonic_begin_ms = now;
  }

  if (ultrasonic_pending && now - ultrasonic_begin_ms >= ULTRASONIC_WAIT_MS)
  {
    ultrasonic_pending = false;
    last_ultrasonic_ms = now;

    float distance_cm = SENSOR_ULTRASONIC.read_end();

    if (distance_cm > 0.0F && distance_cm < WALL_STOP_DISTANCE_CM)
    {
      stop_robot("wall too close");
    }
  }
#endif
}

static constexpr int16_t WIFI_MOVE_DEADZONE = 100;

void command_forward()
{
  if (GAIT.motion() != pluto::motion::MotionCommand::FORWARD)
  {
    GAIT.forward_start(LEGS);
    delay(1000);
  }

  GAIT.set_gait(pluto::motion::GaitKind::TROT);
  GAIT.set_speed(0.65F);
  GAIT.set_motion(pluto::motion::MotionCommand::FORWARD);
  robot_walking = true;

  Serial.println("Motion: forward");
}

void command_backward()
{
  if (GAIT.motion() != pluto::motion::MotionCommand::BACKWARD)
  {
    GAIT.backward_start(LEGS);
    delay(1000);
  }

  GAIT.set_gait(pluto::motion::GaitKind::TROT);
  GAIT.set_speed(0.65F);
  GAIT.set_motion(pluto::motion::MotionCommand::BACKWARD);
  robot_walking = true;

  Serial.println("Motion: backward");
}

void command_turn_left()
{
  GAIT.turnleft_start(LEGS);
  delay(1000);

  GAIT.set_motion(pluto::motion::MotionCommand::LEFT);
  robot_walking = true;

  Serial.println("Motion: turn left");
}

void command_turn_right()
{
  GAIT.turnright_start(LEGS);
  delay(1000);

  GAIT.set_motion(pluto::motion::MotionCommand::RIGHT);
  robot_walking = true;

  Serial.println("Motion: turn right");
}

void command_stop()
{
  GAIT.set_motion(pluto::motion::MotionCommand::IDLE);
  GAIT.stand(LEGS);
  robot_walking = false;

  last_wifi_motion = pluto::motion::MotionCommand::IDLE;
  Serial.println("Motion: stop/stand");
}

void command_bow()
{
  GAIT.bow_start(LEGS);
  delay(250);

  GAIT.set_motion(pluto::motion::MotionCommand::BOW);
  robot_walking = false;

  Serial.println("Motion: bow");
}

void command_sit()
{
  GAIT.sit_start(LEGS);
  delay(250);

  GAIT.set_motion(pluto::motion::MotionCommand::SIT);
  robot_walking = false;

  Serial.println("Motion: sit");
}

void command_paw()
{
  GAIT.set_motion(pluto::motion::MotionCommand::PAW);
  robot_walking = false;

  Serial.println("Motion: paw");
}

void command_flip()
{
  GAIT.set_motion(pluto::motion::MotionCommand::FLIP);
  robot_walking = false;

  Serial.println("Motion: flip");
}

void apply_move_command(int16_t fwd, int16_t side)
{
  if (abs(fwd) < WIFI_MOVE_DEADZONE) fwd = 0;
  if (abs(side) < WIFI_MOVE_DEADZONE) side = 0;

  pluto::motion::MotionCommand new_motion = pluto::motion::MotionCommand::IDLE;

  if (abs(fwd) >= abs(side))
  {
    if (fwd > 0)
      new_motion = pluto::motion::MotionCommand::FORWARD;
    else if (fwd < 0)
      new_motion = pluto::motion::MotionCommand::BACKWARD;
  }
  else
  {
    if (side < 0)
      new_motion = pluto::motion::MotionCommand::LEFT;
    else if (side > 0)
      new_motion = pluto::motion::MotionCommand::RIGHT;
  }

  if (new_motion == last_wifi_motion)
  {
    return;
  }

  last_wifi_motion = new_motion;

  switch (new_motion)
  {
    case pluto::motion::MotionCommand::FORWARD:
      command_forward();
      break;

    case pluto::motion::MotionCommand::BACKWARD:
      command_backward();
      break;

    case pluto::motion::MotionCommand::LEFT:
      command_turn_left();
      break;

    case pluto::motion::MotionCommand::RIGHT:
      command_turn_right();
      break;

    case pluto::motion::MotionCommand::IDLE:
    default:
      command_stop();
      break;
  }
}

void setup()
{
  Serial.begin(115200);

#ifdef PLUTO_ENABLE_WIFI
  PLUTO_SERVER.addAP("Don't Try Plz...", "jules000");
  // TODO: add DELL wifi
  // PLUTO_SERVER.addAP("", "");
  PLUTO_SERVER.begin();
#endif

  PWM.begin();
  PWM.setOscillatorFrequency(27000000);
  PWM.setPWMFreq(50);

#ifdef PLUTO_ENABLE_ULTRASONIC
  SENSOR_ULTRASONIC.begin();
#endif

#ifdef PLUTO_ENABLE_MICROPHONE
  SENSOR_MICROPHONE.begin();
#endif

  GAIT.stand(LEGS);
  Serial.println("Pluto motion ready");
  Serial.println(
      "Commands: f forward, b backward, q turn-left, e turn-right, o flip, h bow, i "
      "sit, s stop, 1 walk, 2 trot, 3 gallop"
      "selected joint");
}

void loop()
{
  static uint32_t last_motion_ms = 0;

  const uint32_t now = millis();

  // update_microphone_control(now);
  update_ultrasonic_control(now);

  if (now - last_motion_ms >= 20)
  {
    GAIT.update(LEGS, now);
    last_motion_ms = now;
  }

  if (Serial.available() > 0)
  {
    uint16_t raw      = LEGS[(uint8_t)CURRENT_SIDE][CURRENT_JOINT].current_raw();
    bool should_print = false;
    char cmd          = Serial.read();

    switch (cmd)
    {
    case 'f':
      GAIT.forward_start(LEGS);
      delay(1000);

      GAIT.set_motion(pluto::motion::MotionCommand::FORWARD);
      robot_walking = true;
      Serial.println("Motion: forward");
      break;
    case 'b':
      GAIT.backward_start(LEGS);
      delay(1000);

      GAIT.set_motion(pluto::motion::MotionCommand::BACKWARD);
      robot_walking = true;
      Serial.println("Motion: backward");
      break;
    case 'q':
      GAIT.turnleft_start(LEGS);
      delay(1000);

      GAIT.set_motion(pluto::motion::MotionCommand::LEFT);
      robot_walking = true;
      Serial.println("Motion: turn left");
      break;
    case 'e':
      GAIT.turnright_start(LEGS);
      delay(1000);

      GAIT.set_motion(pluto::motion::MotionCommand::RIGHT);
      robot_walking = true;
      Serial.println("Motion: turn right");
      break;
    case 'o':
      GAIT.set_motion(pluto::motion::MotionCommand::FLIP);
      Serial.println("Motion: flip");
      break;
    case 'h':
      GAIT.bow_start(LEGS);
      delay(250);
      GAIT.set_motion(pluto::motion::MotionCommand::BOW);
      Serial.println("Motion: bow");
      break;
    case 'i':
      GAIT.sit_start(LEGS);
      delay(250);
      GAIT.set_motion(pluto::motion::MotionCommand::SIT);
      Serial.println("Motion: sit");
      break;
    case 'k':
      GAIT.set_motion(pluto::motion::MotionCommand::PAW);
      Serial.println("Motion: paw");
      break;
    case 's':
      GAIT.set_motion(pluto::motion::MotionCommand::IDLE);
      GAIT.stand(LEGS);
      robot_walking = false;
      Serial.println("Motion: stop/stand");
      break;
    case '1':
      GAIT.set_gait(pluto::motion::GaitKind::WALK);
      Serial.println("Gait: walk");
      break;
    case '2':
      GAIT.set_gait(pluto::motion::GaitKind::TROT);
      Serial.println("Gait: trot");
      break;
    case '3':
      GAIT.set_gait(pluto::motion::GaitKind::GALLOP);
      Serial.println("Gait: gallop");
      break;
    case 'u':
      GAIT.set_walk_manual_phase(!GAIT.walk_manual_phase_enabled());
      Serial.print("Walk manual phase: ");
      Serial.println(GAIT.walk_manual_phase_enabled() ? "ON" : "OFF");
      break;
    case 'm':
      GAIT.next_walk_manual_stage();
      Serial.print("Walk manual stage: ");
      Serial.println(GAIT.walk_manual_stage());
      break;
    case 'j':
      GAIT.next_walk_manual_leg();
      Serial.print("Walk manual leg: ");
      Serial.println(pluto::str_leg_side(GAIT.walk_manual_leg()));
      break;
    case '0':
      GAIT.set_speed(0.0F);
      Serial.println("Speed: 0%");
      break;
    case '5':
      GAIT.set_speed(0.5F);
      Serial.println("Speed: 50%");
      break;
    case '9':
      GAIT.set_speed(1.0F);
      Serial.println("Speed: 100%");
      break;
    case '+':
      LEGS[(uint8_t)CURRENT_SIDE][CURRENT_JOINT].write_raw(raw + 5);
      should_print = true;
      break;
    case '-':
      LEGS[(uint8_t)CURRENT_SIDE][CURRENT_JOINT].write_raw(raw - 5);
      should_print = true;
      break;
    case 'l':
      CURRENT_SIDE = pluto::next_leg_side(CURRENT_SIDE);
      should_print = true;
      break;
    case 'n':
      CURRENT_JOINT = pluto::next_leg_joint_type(CURRENT_JOINT);
      should_print  = true;
      break;
    case 'r':
      LEGS[(uint8_t)CURRENT_SIDE][CURRENT_JOINT].write_starting();
      should_print = true;
      break;
    case 'R':
      LEGS[(uint8_t)CURRENT_SIDE].write_starting();
      Serial.println("Reset all joints");
      break;
    case 'p':
      should_print = true;
      break;
    default:
      // Ignore invalid characters and whitespace
      break;
    }

    if (should_print)
    {
      Serial.print("Leg: ");
      Serial.print(pluto::str_leg_side(CURRENT_SIDE));
      Serial.print(" | Joint: ");
      Serial.print(pluto::str_leg_joint_type(CURRENT_JOINT));
      Serial.print(" | Pulse: ");
      Serial.println(LEGS[(uint8_t)CURRENT_SIDE][CURRENT_JOINT].current_raw());
    }
  }

#ifdef PLUTO_ENABLE_WIFI
  Message msg;
  while (PLUTO_SERVER.getNextMessage(msg))
  {
    switch (static_cast<MessageFamilyKind>(msg.family))
    {
    case MessageFamilyKind::KIND_MOVE:
      switch (static_cast<MessageMoveKind>(msg.kind))
      {
      case MessageMoveKind::MOVE_BY:
      {
        int16_t fwd  = msg.payload.move_by.top_bottom_dir;
        int16_t side = msg.payload.move_by.left_right_dir;

        apply_move_command(fwd, side);
      }
      break;

      case MessageMoveKind::MOVE_STOP_FOR:
        command_stop();
        Serial.println("Command: Stop and Stand");
        break;

      default:
        break;
      }
      break;

    case MessageFamilyKind::KIND_INFO:
      if (msg.kind == static_cast<uint8_t>(MessageInfoKind::INFO_REQUEST_SENSOR))
      {
        if (msg.payload.info_request_sensor.sensor_kind
            == MessageSensorKind::SENSOR_DISTANCE)
        {
  #ifdef PLUTO_ENABLE_ULTRASONIC
          float distance_cm = SENSOR_ULTRASONIC.read_end();

          if (distance_cm > 0.0F)
          {
            uint32_t distance_mm = static_cast<uint32_t>(distance_cm * 10.0F);
            Message reply = pluto::create_sensor_distance(distance_mm, millis());
            PLUTO_SERVER.sendMessage(reply);
          }
  #endif
        }
      }
      break;

    case MessageFamilyKind::KIND_BEHAVIOR:
      switch (static_cast<MessageBehaviorKind>(msg.kind))
      {
      case MessageBehaviorKind::BEHAVIOR_SIT:
        command_sit();
        Serial.println("Behavior: sit requested");
        break;

      case MessageBehaviorKind::BEHAVIOR_GIVE_PAW:
        command_paw();
        Serial.println("Behavior: give paw");
        break;

      case MessageBehaviorKind::BEHAVIOR_FLIP:
        command_flip();
        Serial.println("Behavior: flip");
        break;

      case MessageBehaviorKind::BEHAVIOR_BOW:
        command_bow();
        Serial.println("Behavior: lie down requested");
        break;

      default:
        break;
      }
      break;

    default:
      break;
    }
  }
#endif
}

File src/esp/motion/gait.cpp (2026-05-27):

#include <motion/gait.h>

#include <Arduino.h>
#include <cmath>
#include <motion/ik_solver.h>

namespace pluto::motion
{
  namespace
  {
    constexpr float COXA_LENGTH  = 7.00F;
    constexpr float FEMUR_LENGTH = 12.00F;
    constexpr float TIBIA_LENGTH = 13.50F;

    constexpr float FOOT_Z_STAND = -23.0F; // standing height

    constexpr float SHIFT_END                = 0.25F;
    constexpr float LIFT_END                 = 0.50F;
    constexpr float STEP_END                 = 0.75F;
    constexpr float PHASE_QUANTIZATION_STEPS = 40.0F;
    constexpr float FOOT_X_QUANTIZATION_STEP = 0.25F;
    constexpr float FOOT_Z_QUANTIZATION_STEP = 0.25F;

    constexpr float STRIDE = 1.80F;
    constexpr float LIFT   = 3.20F;

    constexpr float FOOT_Y_STANCE               = 7.00F;
    constexpr float WALK_FRONT_STRIDE_SCALE     = 0.82F;
    constexpr float WALK_REAR_STRIDE_SCALE      = 0.82F;
    constexpr int32_t WALK_LF_FEMUR_FLAT_MD     = 30000;
    constexpr float BOW_FRONT_DROP              = 5.00F;
    constexpr float BOW_REAR_RISE               = 2.00F;
    constexpr float BOW_FRONT_BACK              = 1.50F;
    constexpr float BOW_PERIOD                  = 2.00F;

    constexpr float PAW_REST_X               = 1.20F;
    constexpr float PAW_REST_Z               = -16.20F;
    constexpr float PAW_PEAK_X               = 2.60F;
    constexpr float PAW_PEAK_Z               = -15.20F;
    constexpr float PAW_PERIOD               = 1.40F;
    constexpr float PAW_SHIFT_Y              = 1.60F;
    constexpr float PAW_REAR_SUPPORT_DROP_Z  = 1.80F;
    constexpr float PAW_FRONT_SUPPORT_BACK_X = -1.00F;

    constexpr bool is_right_side(LegSide side) noexcept
    {
      return side == LegSide::TOP_RIGHT || side == LegSide::BOTTOM_RIGHT;
    }

    constexpr bool is_front_side(LegSide side) noexcept
    {
      return side == LegSide::TOP_LEFT || side == LegSide::TOP_RIGHT;
    }

    float normalized_phase(float time_s, float period_s, float offset) noexcept
    {
      float phase = fmodf(time_s / period_s + offset, 1.0F);
      if (phase < 0.0F)
      {
        phase += 1.0F;
      }

      return phase;
    }

    float quantize_step(float value, float step) noexcept
    {
      if (step <= 0.0F)
      {
        return value;
      }

      return roundf(value / step) * step;
    }

    float quantize_phase(float phase) noexcept
    {
      if (PHASE_QUANTIZATION_STEPS <= 0.0F)
      {
        return phase;
      }

      return roundf(phase * PHASE_QUANTIZATION_STEPS) / PHASE_QUANTIZATION_STEPS;
    }

    float smoothstep(float t) noexcept
    {
      return t * t * (3.0F - 2.0F * t);
    }

    float catmull_rom(
        float p0, float p1, float p2, float p3, float t) noexcept
    {
      const float t2 = t * t;
      const float t3 = t2 * t;
      return 0.5F
             * ((2.0F * p1) + (-p0 + p2) * t
                + (2.0F * p0 - 5.0F * p1 + 4.0F * p2 - p3) * t2
                + (-p0 + 3.0F * p1 - 3.0F * p2 + p3) * t3);
    }

    float wrap_phase(float phase) noexcept
    {
      float wrapped = fmodf(phase, 1.0F);
      if (wrapped < 0.0F)
      {
        wrapped += 1.0F;
      }

      return wrapped;
    }

    float side_stance_y(LegSide side) noexcept
    {
      return is_right_side(side) ? -FOOT_Y_STANCE : FOOT_Y_STANCE;
    }

    FootTarget foot_from_phase(
        float phase, float forward_scale, float foot_y, float stride, float lift,
        float z_stand) noexcept
    {
      if (phase < SHIFT_END)
      {
        const float t = phase / SHIFT_END;
        return {(stride * smoothstep(t)) * forward_scale, foot_y, z_stand};
      }

      if (phase < LIFT_END)
      {
        const float t = (phase - SHIFT_END) / (LIFT_END - SHIFT_END);
        return {
            stride * forward_scale, foot_y, z_stand + lift * sinf(0.5F * PI * t)};
      }

      if (phase < STEP_END)
      {
        const float t = (phase - LIFT_END) / (STEP_END - LIFT_END);
        return {
            (stride - 2.0F * stride * smoothstep(t)) * forward_scale, foot_y,
            z_stand + lift * cosf(0.5F * PI * t)};
      }

      const float t = (phase - STEP_END) / (1.0F - STEP_END);
      return {(-stride * (1.0F - smoothstep(t))) * forward_scale, foot_y, z_stand};
    }

    FootTarget foot_from_phase_interpolated(
        float phase, float forward_scale, float foot_y, float stride, float lift,
        float z_stand) noexcept
    {
      const float wrapped_phase = wrap_phase(phase);
      const float steps         = fmaxf(2.0F, PHASE_QUANTIZATION_STEPS);
      const float dt            = 1.0F / steps;
      const float pos           = wrapped_phase * steps;
      const float base_idx      = floorf(pos);
      const float t             = pos - base_idx;

      const float p0 =
          wrap_phase((base_idx - 1.0F) * dt);
      const float p1 =
          wrap_phase(base_idx * dt);
      const float p2 =
          wrap_phase((base_idx + 1.0F) * dt);
      const float p3 =
          wrap_phase((base_idx + 2.0F) * dt);

      const auto f0 =
          foot_from_phase(p0, forward_scale, foot_y, stride, lift, z_stand);
      const auto f1 =
          foot_from_phase(p1, forward_scale, foot_y, stride, lift, z_stand);
      const auto f2 =
          foot_from_phase(p2, forward_scale, foot_y, stride, lift, z_stand);
      const auto f3 =
          foot_from_phase(p3, forward_scale, foot_y, stride, lift, z_stand);

      return {
          catmull_rom(f0.x, f1.x, f2.x, f3.x, t),
          catmull_rom(f0.y, f1.y, f2.y, f3.y, t),
          catmull_rom(f0.z, f1.z, f2.z, f3.z, t)};
    }

    JointAnglesMd solve_leg(FootTarget foot, LegSide side) noexcept
    {
      const float signed_coxa = is_right_side(side) ? -COXA_LENGTH : COXA_LENGTH;
      return to_millidegrees(
          solve_ik(foot, signed_coxa, FEMUR_LENGTH, TIBIA_LENGTH));
    }

    constexpr const char* leg_name(LegSide side) noexcept
    {
      switch (side)
      {
      case LegSide::TOP_LEFT:
        return "TL";
      case LegSide::TOP_RIGHT:
        return "TR";
      case LegSide::BOTTOM_LEFT:
        return "BL";
      case LegSide::BOTTOM_RIGHT:
        return "BR";
      default:
        return "??";
      }
    }

    int32_t raw_to_angle_md(const JointConfig& config, uint16_t raw) noexcept
    {
      uint16_t normalized_raw = raw;
      if (config.inverted)
      {
        normalized_raw = config.raw_max - (raw - config.raw_min);
      }

      return config.angle_min_md
             + static_cast<int32_t>(
                 static_cast<int64_t>(normalized_raw - config.raw_min)
                 * static_cast<int64_t>(config.angle_max_md - config.angle_min_md)
                 / static_cast<int64_t>(config.raw_max - config.raw_min));
    }

    uint16_t raw_for_motion(const JointConfig& config, MotionCommand motion) noexcept
    {
      switch (motion)
      {
      case MotionCommand::FORWARD:
      case MotionCommand::RIGHT:
        return config.raw_forward;
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

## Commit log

2026-03-19 Added leg code
2026-04-02 feat: switch control buttons to press-and-hold
2026-04-15 Fix: remove camera reset
2026-04-29 Add HC-SR04 ultrasonic sensor test code
2026-04-29 feat: use stl body
    [Femur.stl, body.stl, coxa.stl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]
2026-04-30 Update ESP32 PlatformIO configuration
2026-05-06 Added LegJointType/LegSide and Leg class
2026-05-06 Added new APIs to Leg
2026-05-06 fix: stl body in the simulation (old design)
2026-05-06 add: updated asset files
    [Femur.stl, body.stl, coxa.stl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]
2026-05-07 Added 4 legs test
2026-05-07 Added ultrasonic sensor that uses interrupts
2026-05-08 Added and tested sensors
2026-05-11 Added test for both sensors
2026-05-13 Updated leg data
2026-05-13 Refactored \legs folder to improve abstraction.
2026-05-14 fix: use FOOT_Z_STAND only
    [gait.cpp, main.cpp]
2026-05-14 ✅ unstable walking
2026-05-16 test: walk calibration (LF servos need to be fixed)
    [gait.cpp, main.cpp]
2026-05-19 ✅ correct raw_start values
2026-05-19 First version of the assembly instructions
2026-05-19 ✅ calibrating
2026-05-19 ✅ final raw values for standing position
2026-05-19 fix: use different offsets for each joint
2026-05-20 Update servo limits after recalibration
2026-05-20 fix: use correct `standing_offset` for the joints
    [gait.cpp]
2026-05-20 Added initial sensor README
2026-05-20 Added more info about sensors
2026-05-20 fix: fewer foot trajectory samples
    [main.cpp]
2026-05-20 fix: quantize phase and foot.xz
    [gait.cpp]
2026-05-21 Exported robot to MJCF format
    [Femur.stl, bl_coxa.stl, bl_femur.stl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]
2026-05-21 🔥 PLUTO WALKS FORWARD !!
2026-05-22 fix: use correct for bottom servos
    [gait.cpp]
2026-05-22 Update servo limits and resting positions
2026-05-22 Added PWM include and changed to steady_clock
2026-05-22 fix: added std::chrono to duration_cast call
    [sim.cpp]
2026-05-22 Added mock PWM driver for simulation
2026-05-23 Add clap control and ultrasonic safety stop
2026-05-25 Fix ESP32 build by excluding simulation sources
2026-05-25 Update clap detection and ultrasonic distance threshold
2026-05-25 Moved sim folder and made simulaton framerate independent
2026-05-26 Enhance assembly instructions with images and details
    Added images and clarified assembly steps for TIBIA, FEMUR, and COXA.
2026-05-26 Update leg calibration values
2026-05-26 Removed the electrical circuit image
2026-05-26 align Pluto documentation with current firmware and simulation state
2026-05-26 Update leg calibration values (second part)
2026-05-26 removed the old electrical circuit diagram
2026-05-26 Added 3d print mesh and changed folder name of mesh to simulation mesh
    [Back Left Bar.stl, Back Left COXA.stl, Back Left Inner FEMUR.stl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]
2026-05-26 docs: improve build handoff and clean up assembly assets
2026-05-26 Changed CMakeLists.txt, moved simulation mesh files, and updated sim_gait.cpp and sim_main.cpp to reflect new file structure and add debug output.
    [bl_coxa.stl, bl_femur.stl, bl_tibia.stl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]
2026-05-26 ✅ walk straight
2026-05-27 Update ultrasonic obstacle stop threshold
2026-05-27 Final circuit diagram
2026-05-27 sim: added camera controls and removed constraints in robot description
2026-05-27 Update leg calibration values (with TPU)
2026-05-27 Use motion-specific leg offsets for gait control
2026-05-27 Adjust leg positions for turning behavior
2026-05-27 🔥 Pluto can go foward, turn left/right
2026-05-27 sim: simulation works fully
    [bl_tibia.stl, br_tibia.stl, tl_tibia.stl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]
2026-05-27 Pluto can do a flip
    [gait.cpp, main.cpp, sim_gait.cpp]
2026-05-27 🐾 Pluto can sit down
2026-05-27 Add stl files for the body
    [Board Holder.stl, Main Body.stl, Sensor Holder.stl]
2026-05-27 Update CAD_FILES.md with additional part details
    Added information about additional printable parts for the main body and holders.
2026-05-27 updated the cad files to match readme files
2026-05-27 Added TPU foot file
    [TPU Foot.stl]
2026-05-27 added full body cad image
2026-05-27 docs: update WiFi movement and CAD asset documentation
2026-05-28 Updated buttons to use new enums
2026-05-28 Fixed switch to use new MessageBehaviorKind
    [main.cpp]
2026-05-28 CAD modified
2026-05-28 controller: added flip command
    [main.cpp]
